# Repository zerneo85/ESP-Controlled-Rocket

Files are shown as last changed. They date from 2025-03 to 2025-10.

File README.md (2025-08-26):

# ESP Controlled Rocket

The ESP Controlled Rocket repository documents an advanced, ESP32-powered flight computer and 3D-printed rocket design. The project provides open-source firmware, electronics, and mechanical files to launch, track, and safely recover water rockets made from plastic bottles—ranging from simple mechanically-triggered parachute releases to full telemetry-enabled, software-controlled deployments.

---

## Table of Contents
- [ESP Controlled Rocket](#esp-controlled-rocket)
  - [Table of Contents](#table-of-contents)
  - [Introduction](#introduction)
  - [Rocket Variants](#rocket-variants)
    - [Rocket A](#rocket-a)
    - [Rocket B](#rocket-b)
  -  [Splicing Bottles](https://zerneo85.github.io/ESP-Controlled-Rocket/Water-Rocket-Splice-Bilingual.html)
- [ESP Controlled Rocket](#esp-controlled-rocket-1)
  - [Flight Computer](#flight-computer)
    - [Features](#features)
    - [LED Status Indicators](#led-status-indicators)
    - [Code Overview](#code-overview)
    - [Screenshots](#screenshots)
      - [Dashboard, File Manager, and Visualization](#dashboard-file-manager-and-visualization)
  - [3D Parts \& Downloads](#3d-parts--downloads)
    - [Parts Overview (Summary)](#parts-overview-summary)
  - [Assembly \& Build](#assembly--build)
  - [Usage](#usage)
    - [Setting Up the Flight Computer](#setting-up-the-flight-computer)
    - [Setting Triggers](#setting-triggers)
    - [SPIFFS Logging](#spiffs-logging)
  - [Rocket Performance (Simulation Results)](#rocket-performance-simulation-results)
    - [Water Rocket Performance Table (8 bar, realistic empty mass)](#water-rocket-performance-table-8-bar-realistic-empty-mass)
      - [Assumptions/Notes:](#assumptionsnotes)
  - [References \& Further Simulation](#references--further-simulation)
  - [Rocket Weight](#rocket-weight)
  - [Release Notes](#release-notes)
    - [v3.7.0](#v370)
  - [Contributing](#contributing)

---

## Introduction

The **ESP Controlled Rocket** project combines embedded firmware and printable parts for building water rockets with real-time telemetry, logging, and parachute deployment.  
There are two rocket builds:

- **Rocket A:** 1 bottle, mechanical parachute release (no electronics)
- **Rocket B:** 3 × 1.5L bottles, ESP32-based telemetry, automatic parachute deployment, and advanced data logging.

---

## Rocket Variants

### Rocket A

- Single PET bottle
- Mechanical parachute release
- See [docs/aircommandrockets_simulator_rocket_a.pdf](https://github.com/zerneo85/ESP-Controlled-Rocket/tree/main/docs/aircommandrockets_simulator_rocket_a.pdf) for simulation results

### Rocket B

- Three or more 1.5-liter PET bottles
- ESP32 flight computer with:
  - Telemetry (altitude, acceleration, orientation, etc.)
  - Web dashboard (WiFi)
  - Automatic and manual parachute deployment
  - Data logging (SD card + SPIFFS)
  - RGB LED status ring
  - **Automatic location/pressure/height fetching from OpenWeather API**
  - **Location and reference pressure/height can be updated on-the-fly from the web dashboard**
- See [docs/aircommandrockets_simulator_rocket_b.pdf](https://github.com/zerneo85/ESP-Controlled-Rocket/tree/main/docs/aircommandrockets_simulator_rocket_b.pdf) for simulation results

---

# ESP Controlled Rocket

...

## Flight Computer

### Features

- **Sensor Integration:**  
  - BMP280 (temperature, pressure, altitude)
  - MPU6050 (acceleration, gyroscope, temp)
- **Real-Time Telemetry:**  
  - WebSocket data streaming (altitude, acceleration, deployment state, battery, etc.)
- **Location & Atmospheric Reference:**  
  - **Automatically retrieves location and reference pressure/height from the OpenWeather API**
  - **Location and reference data can be updated live via the web dashboard** for accurate altitude and pressure calculations
- **Parachute Deployment:**  
  - Triggered by detected altitude drop or settable parameters
  - Manual override via dashboard
- **Dual Logging:**  
  - Logs flight and events to both SD card and SPIFFS (onboard flash)
  - Warns user if SPIFFS is full or nearly full
- **RGB LED Ring:**  
  - Multicolor status feedback for boot, WiFi, arming, flight, deployment, errors
- **OTA Updates:**  
  - Firmware can be updated via HTTP web interface
- **Web File Management:**  
  - Upload/download/delete files on SD card and SPIFFS
- **3D Visualization Support:**  
  - Streams orientation/telemetry for optional real-time display
  - **Since v3.7.0:** Visualization assets are stored directly in SPIFFS for faster access and easier deployment
- **Configurable Triggers:**  
  - Set altitude, descent, and arming conditions via web dashboard
- **Time Synchronization:**  
  - NTP for accurate timestamps
- **Flexible Axis Orientation:**  
  - Change IMU axes in software for different mounting positions
- **Improved Web Dashboard (v3.7.0):**  
  - Dashboard HTML, CSS, and JS files are now hosted from SPIFFS memory instead of flash-coding, reducing firmware size and simplifying updates.

...

### LED Status Indicators

The onboard RGB LED ring signals various states:

| State | LED Effect |
|---|---|
| Power-on/Boot | Spinning blue |
| Connecting to WiFi | Blinking yellow |
| Access Point mode | Blinking orange |
| WiFi Connected | Solid green |
| Arming parachute | Pulsing teal |
| Parachute armed (standby) | Solid blue |
| Parachute released | Red flash, then solid red |
| Logging active (SD/SPIFFS) | Brief white blink on each write |
| Error (sensor, SD, SPIFFS) | Flashing red |
| OTA update in progress | Spinning purple |
| SPIFFS almost full | Alternating red/white flash |
| SPIFFS/SD full or write fail  | Fast flashing red |

**Note:** All LED sequences are customizable in the firmware.

---

### Code Overview

The main firmware is organized as follows:

- **Sensor Management**  
  Handles initialization, calibration, and continuous reading of BMP280 and MPU6050 sensors. Includes zeroing/calibration routines (triggered via dashboard) and monitoring for sensor errors or drift.
- **Data Processing**  
  Processes raw sensor data: applies filtering, calculates true altitude (using local or API pressure reference), computes speed, acceleration, and detects launch/apogee/descent events. Also manages state transitions for arming and flight.
- **Parachute Control**  
  Evaluates trigger logic for parachute release based on configurable parameters (altitude drop, time, speed, etc.), and actuates the servo. Also handles manual overrides.
- **LED Status Indicators**  
  Drives the RGB LED ring with appropriate effects for all operational, error, and feedback states.
- **Communication**  
  Runs a web server and WebSocket interface for live telemetry, file management, trigger config, and OTA updates.
- **Web-Based File Management**  
  Lets you view, upload, download, or delete files from both SD card and SPIFFS through the web UI ([flight-computer/data/index.html](https://github.com/zerneo85/ESP-Controlled-Rocket/tree/main/flight-computer/data/index.html)).
- **3D Visualization Support**  
  Broadcasts orientation/quaternion and motion data for an optional web-based real-time 3D rocket visualization (experimental).
- **Logging**  
  Logs all flight events, sensor data, state transitions, and errors to SD card and SPIFFS, with backup and rollover if space runs out. Warns if SPIFFS is almost full.
- **Configurable Axis Orientation**  
  IMU axes can be reassigned at runtime via the dashboard for flexible installation.
- **Live Location Overrides**  
  Location (lat/lon) and pressure reference can be set/changed from the web interface, which updates all altitude and weather calculations instantly.  
- **OTA Updates**  
  Supports uploading new firmware from the web interface, including status feedback via LED.

See [`flight-computer/flight-computer.ino`](https://github.com/zerneo85/ESP-Controlled-Rocket/tree/main/flight-computer/flight-computer.ino) and related modules for implementation details.

---

### Screenshots

#### Dashboard, File Manager, and Visualization
All dashboards video  
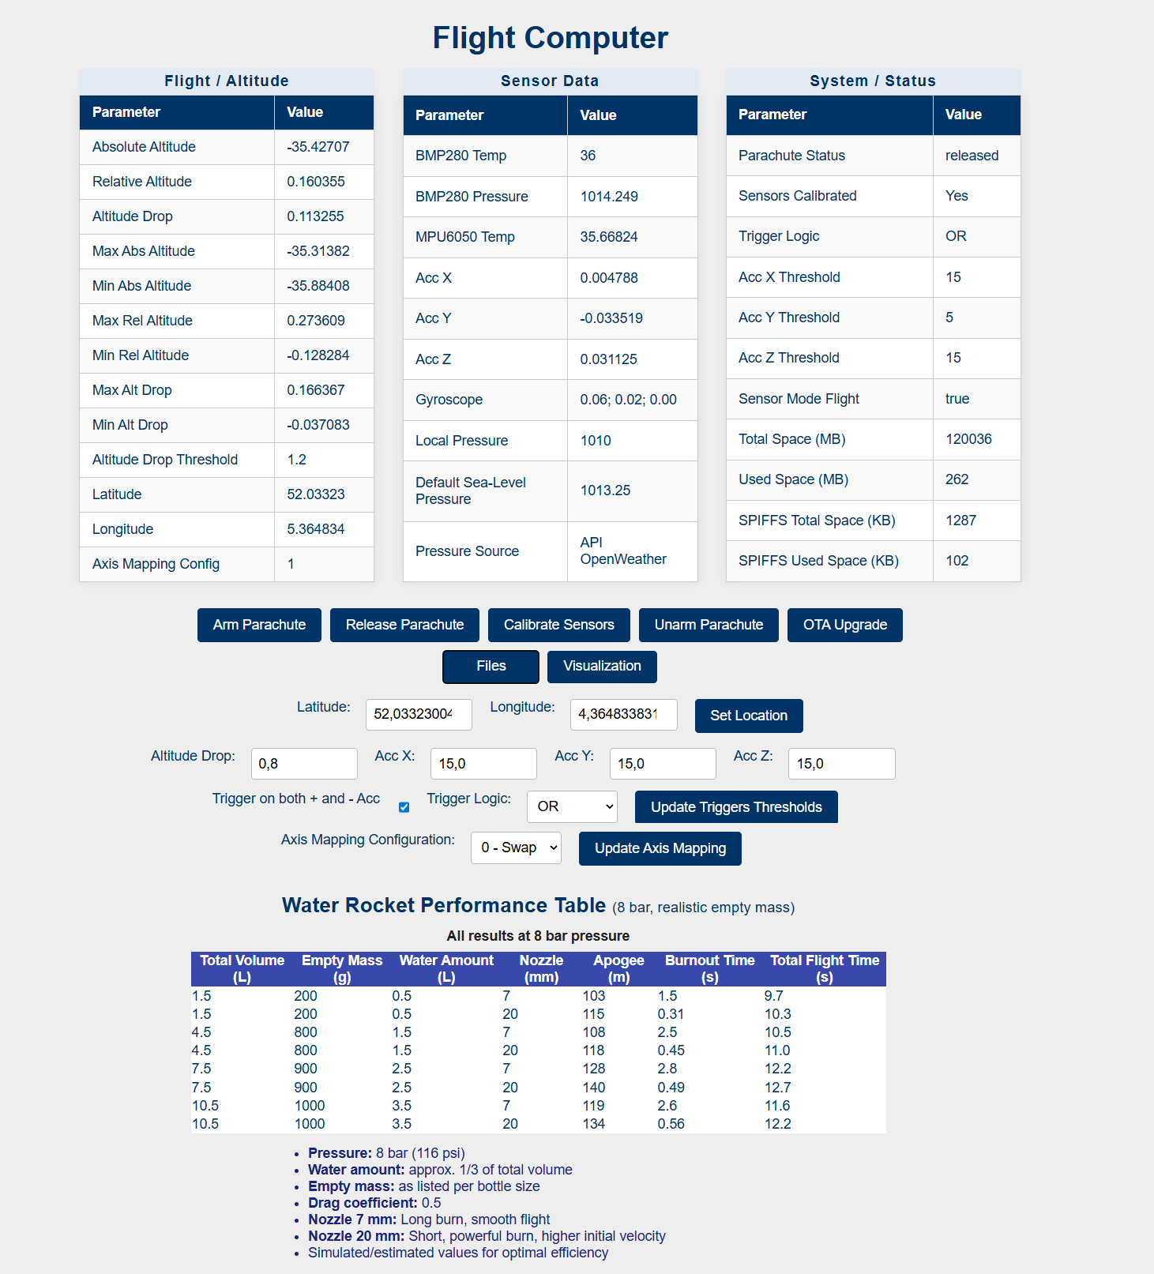
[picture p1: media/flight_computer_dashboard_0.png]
Flight Computer Screenshot
  
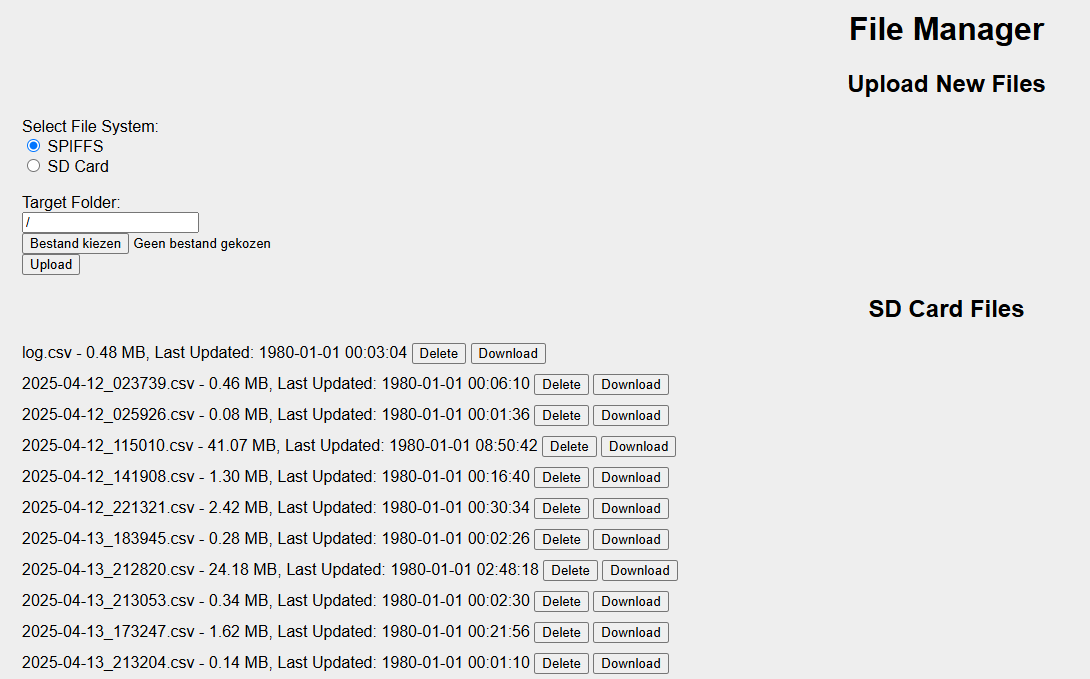
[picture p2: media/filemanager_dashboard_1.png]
File Manager Screenshot
  
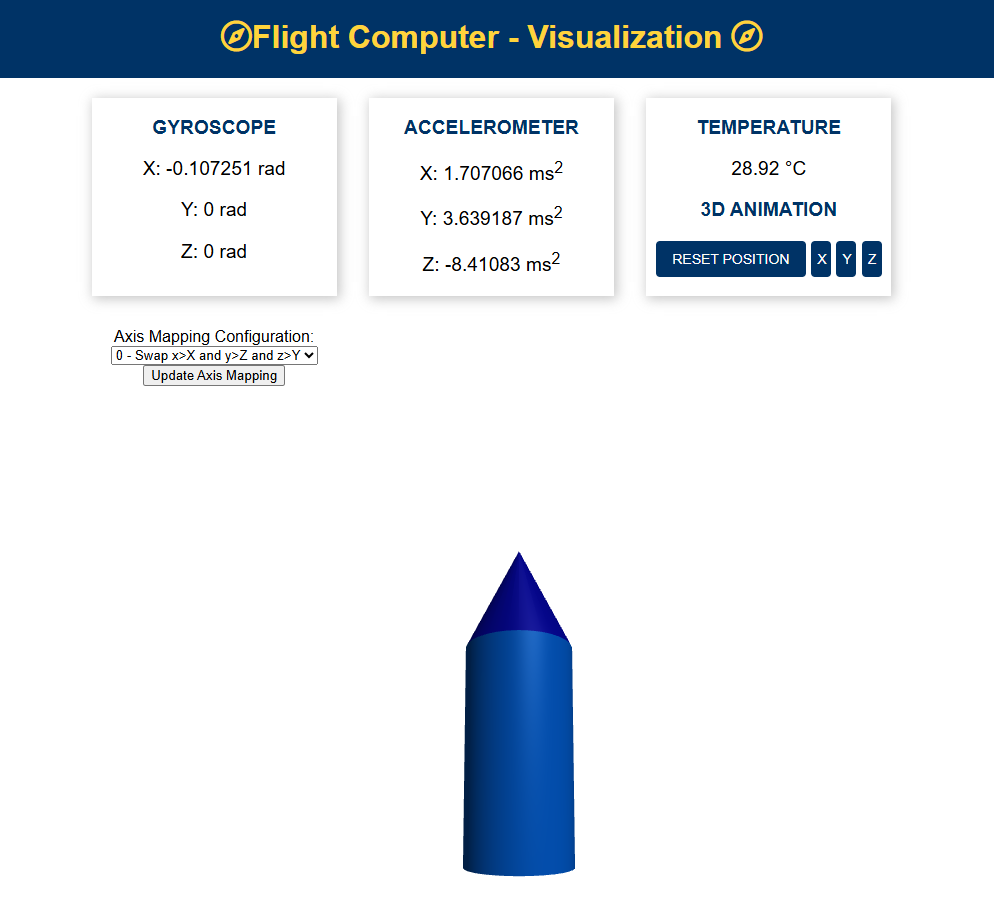
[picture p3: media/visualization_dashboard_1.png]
Visualization Screenshot
  
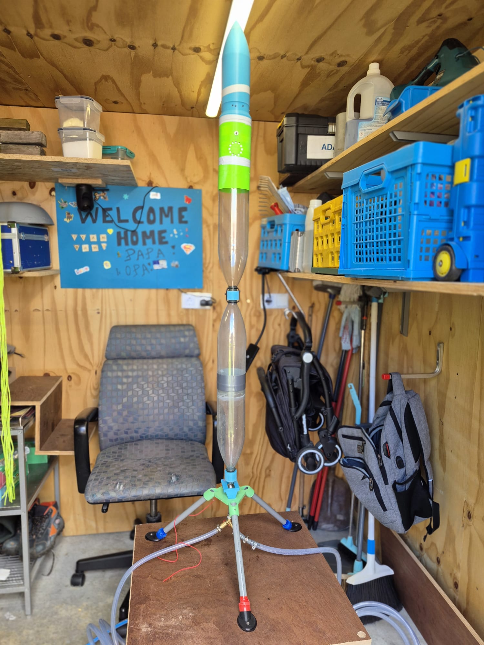
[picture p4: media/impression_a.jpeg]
Impression A
 
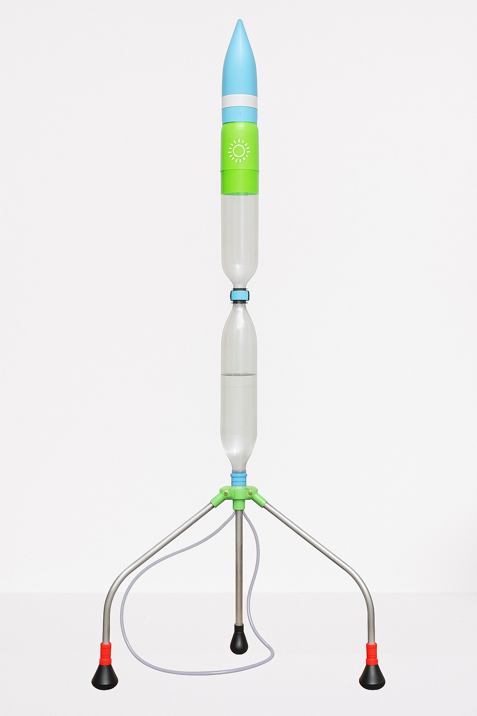
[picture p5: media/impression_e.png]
Impression E
  
Payload Parachute Release Video  

---

## 3D Parts & Downloads

All 3D-printable parts for the ESP Controlled Rocket are available:

- **Repository:** [`/3d-designs/`](https://github.com/zerneo85/ESP-Controlled-Rocket/tree/main/3d-designs/) – STL files with exact filenames as listed
- **Tinkercad Project:** [Soda Water Bottle Rocket Air Pressure](https://www.tinkercad.com/things/2OLB51qPn6D-soda-bottle-rocket-air-pressure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)  
  *(note: transparent parts represent older versions)*
- **Thingiverse:** [Soda Water Bottle Rocket Air Pressure](https://www.thingiverse.com/thing:7127173)

### Parts Overview (Summary)

Below is a categorized overview of the 3D-printable parts.  
For the **complete list with detailed descriptions and references**, see [docs/3d_parts_overview.md](https://github.com/zerneo85/ESP-Controlled-Rocket/tree/main/docs/3d_parts_overview.md).

| Use Category | Colors |
|---|---|
| Bottle & Nozzle & Hose Connectors | Orange |
| Fins | Dark Purple, Light Purple |
| Launching Platform Air Pressure Release | Dark Green |
| Launching Platform Cable Tie Release  | Green |
| Parachute Ejection Module | Blue |
| Payload Enclosure | Yellow |
| Rail Guide Mount | Red |
| Servo Arms | Light Green |
| Simple Rocket & Parachute Module | Gray |

---

## Assembly & Build

See [`docs/assembly_guide.md`](https://github.com/zerneo85/ESP-Controlled-Rocket/tree/main/docs/assembly_guide.md) for wiring, assembly, and mounting tips.

---

## Usage

### Setting Up the Flight Computer

1. **WiFi Configuration:**  
   - Edit WiFi credentials in [`flight-computer/flight-computer.ino`](https://github.com/zerneo85/ESP-Controlled-Rocket/tree/main/flight-computer/flight-computer.ino)
   - If WiFi fails, device enters Access Point mode (see [LED Status Indicators](#led-status-indicators))

2. **Calibrating Sensors:**  
   - Use the dashboard to trigger IMU and barometric sensor calibration/zeroing.
   - Axis alignment (for IMU) can be changed from the web interface and saved for next boot.

3. **Changing Axis / IMU Orientation:**  
   - In the dashboard, select the mounting orientation that matches your build.
   - The firmware applies the corresponding transformation to all motion data.

4. **Changing Triggers:**  
   - All parachute triggers (arming/release altitude, speed, time) can be set via the web interface, or changed in the config section of [`flight-computer.ino`](https://github.com/zerneo85/ESP-Controlled-Rocket/tree/main/flight-computer/flight-computer.ino).

5. **Changing Location & Weather Reference:**  
   - Update launch site coordinates and pressure reference directly from the dashboard.
   - Device can fetch current weather/pressure using the OpenWeather API.
   - All calculations (altitude, apogee, trigger) immediately reflect the new data.

6. **3D Visualization:**  
   - Enable the real-time 3D view from the web UI for attitude/flight path visualization.

7. **OTA Updates:**  
   - Web-based firmware upload (see dashboard)

8. **Manual Parachute Release:**  
   - Use “Arm” and “Release” buttons on the web dashboard

9. **File Management:**  
   - Upload/download/delete logs via the web interface (SD + SPIFFS)

---

### Setting Triggers

All parachute release and arming triggers are **configurable via the web dashboard**:

- **Arming:** Set minimum altitude, minimum time after launch, or minimum vertical speed
- **Release:** Configure required altitude drop (relative or absolute), minimum speed, and/or custom sensor thresholds
- **Manual override** is always available from the dashboard

To change default trigger parameters in code, edit the config section in [`flight-computer/flight-computer.ino`](https://github.com/zerneo85/ESP-Controlled-Rocket/tree/main/flight-computer/flight-computer.ino).

---

### SPIFFS Logging

- **All critical events and telemetry** are logged to both SD card and SPIFFS (flash memory) as backup.
- If SPIFFS free space drops below 10%, a **red/white alternating LED flash** warns the user. If full, **fast red flashing** and a dashboard warning are triggered; logging pauses until space is freed.
- SPIFFS logs can be downloaded/deleted from the File Manager page in the web UI.
- **Since v3.7.0:** The complete web dashboard and visualization interface are also stored in SPIFFS. This enables updates of UI components without reflashing the firmware.

---

## Rocket Performance (Simulation Results)

Full details for both rocket builds are in the simulation PDFs, generated with [Air Command Rocket Simulator](http://www.aircommandrockets.com/sim/simulator.htm):

| Variant | PDF | Volume (L) | Water (L) | Empty Mass (g) | Nozzle (mm) | Peak Altitude (m) | Notes |
|---|--- |--- |--- |--- |--- |--- |---|
| Rocket A  | [docs/aircommandrockets_simulator_rocket_a.pdf](https://github.com/zerneo85/ESP-Controlled-Rocket/tree/main/docs/aircommandrockets_simulator_rocket_a.pdf) | 1.5 | 0.5 | 198 | 7 | 67.7 | Mechanical  |
| Rocket B  | [docs/aircommandrockets_simulator_rocket_b.pdf](https://github.com/zerneo85/ESP-Controlled-Rocket/tree/main/docs/aircommandrockets_simulator_rocket_b.pdf) | 4.5 | 1.0 | 803 | 7 | 50.0 | ESP32/auto  |

- *See PDFs in [`docs/`](https://github.com/zerneo85/ESP-Controlled-Rocket/tree/main/docs/) for full simulation graphs and breakdown.*
- *For further/different setups, use the [Air Command Rocket Simulator](http://www.aircommandrockets.com/sim/simulator.htm).*

### Water Rocket Performance Table (8 bar, realistic empty mass)

| Total Volume (L) | Empty Mass (g) | Water Amount (L) | Nozzle (mm) | Apogee (m) | Burnout Time (s) | Total Flight Time (s) |
|:---:|:---:|:---:|:---:|:---:|:---:|:---:|
| 1.5 | 200 | 0.5 | 7 | 103 | 1.5 |  9.7 |
| 1.5 | 200 | 0.5 | 20 | 115 | 0.31 |  10.3 |
| 4.5 | 800 | 1.5 | 7 | 108 | 2.5 |  10.5 |
| 4.5 | 800 | 1.5 | 20 | 118 | 0.45 |  11.0 |
| 7.5 | 900 | 2.5 | 7 | 128 | 2.8 |  12.2 |
| 7.5 | 900 | 2.5 | 20 | 140 | 0.49 |  12.7 |
| 10.5 | 1000 | 3.5 | 7 | 119 | 2.6 |  11.6 |
| 10.5 | 1000 | 3.5 | 20 | 134 | 0.56 |  12.2 |

#### Assumptions/Notes:
- Pressure: **8 bar** (116 psi)
- Water amount: ~**1/3 of total volume**
- Empty mass: As shown for each bottle size
- Drag coefficient: **0.5**
- Nozzle: **7 mm** (long burn, smooth flight), **20 mm** (short, powerful burn, higher velocity)
- Simulated/estimated values (for best-case efficiency)

---

## References & Further Simulation

- [Air Command Rocket Simulator](http://www.aircommandrockets.com/sim/simulator.htm) – Advanced web-based tool for bottle rocket performance prediction and optimization
- [`docs/aircommandrockets_simulator_rocket_a.pdf`](https://github.com/zerneo85/ESP-Controlled-Rocket/tree/main/docs/aircommandrockets_simulator_rocket_a.pdf) (Rocket A)
- [`docs/aircommandrockets_simulator_rocket_b.pdf`](https://github.com/zerneo85/ESP-Controlled-Rocket/tree/main/docs/aircommandrockets_simulator_rocket_b.pdf) (Rocket B)

---

## Rocket Weight

See [`docs/rocket_parts.xlsx`](https://github.com/zerneo85/ESP-Controlled-Rocket/tree/main/docs/rocket_parts.xlsx) for weight of the individual parts.

## Release Notes

### v3.7.0
- Moved **dashboard and visualization files** into **SPIFFS memory**:
  - Frees up firmware space  
  - Allows updating of UI components via SPIFFS file manager  
  - Faster load times for dashboards and visualizations
- Improved maintainability by separating UI assets from firmware code
- Minor bug fixes and optimizations

## Contributing

Contributions are welcome! Please:
- Fork the repository
- Use feature branches
- Write clear commit messages
- Submit pull requests with a detailed description

---

_Questions, suggestions, or want extra details? Open an issue or reach out!_

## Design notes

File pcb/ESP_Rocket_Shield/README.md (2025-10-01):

# ESP Rocket Shield — KiCad Starter Project (Rev A)

This is a **starter** KiCad 8 project for your ESP32‑S3 rocket shield. It includes a schematic with all blocks you requested (power with L7805, I²C sensors (BMP280/MPU6050 class), LED pads, piezo buzzer, and dual female headers for the ESP32‑S3 dev board). 
The PCB file contains the board outline and class definitions; import/update from the schematic to populate footprints as you finalize.

> **Note**: This scaffold is intentionally minimal so you can adjust footprints to your exact parts. Nets, labels, and blocks are provided; please run **Tools → Annotate**, then **Assign Footprints**, then **Update PCB from Schematic**.

## Quick steps
1. Open `ESP_Rocket_Shield.kicad_pro` in KiCad 8+.
2. Open the schematic. Check/replace sensor symbols if you choose BMP388/DPS310/ICM‑42688 instead of BMP280/MPU6050.
3. Use **Assign Footprints** to bind footprints that match your inventory (headers, LGA packages, buzzer, etc.).
4. Run **Update PCB from Schematic** to bring parts into PCB.
5. Route, pour GND, add stitching vias, and finalize thermals on L7805.
6. Generate Gerbers.

## Nets / pins (matches your firmware & diagram)
- LED data: **GPIO17** → `LED_DATA` → series **330 Ω** → LED pad.
- I²C: **GPIO42= SDA**, **GPIO37= SCL**, with **4.7 kΩ** pull‑ups to **3V3**.
- Buzzer: **GPIO21** → 1 kΩ → N‑MOSFET/NPN → Active buzzer to **+5V**.
- Servo (optional): **GPIO14** → 3‑pin header (+5V / PWM / GND).
- Power: **VIN** (2S Li‑ion) → Fuse → Schottky (reverse) → **L7805** → **+5V** rail.
- ESP32 gets power via **5V** dev board pin; sensors on **3V3** from the dev board.

## Library picks
- L7805: `Regulator_Linear:L7805` symbol; footprint TO‑220 or TO‑252.
- Baro: `Sensor_Pressure:BMP280` (swap to BMP388/DPS310 later if you prefer).
- IMU: `Sensor_Motion:MPU-6050` (swap to ICM‑42688‑P if you prefer).
- Headers: `Connector_Generic:Conn_01x19_Female` left/right for ESP32‑S3; `Conn_01x03` for LED and Servo.
- Buzzer driver: `Device:Q_NMOS_GSD` (2N7002) or `Device:Q_NPN_BEC` (MMBT2222A).

## Board outline
The PCB is initialized as 90×40 mm with 4× M2.5 mounting holes. Adjust to fit your airframe.

## Notes
- Place the IMU and barometer near the board center, away from the buzzer and power edges.
- Keep a vent hole under the barometer and cover with open‑cell foam after assembly.
- If LED current > ~0.6–0.8 A and VIN ≈ 2S (7–8.4 V), consider swapping L7805 for a buck converter footprint to reduce heat.

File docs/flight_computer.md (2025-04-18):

# Flight Computer Documentation

This document provides a detailed explanation of the flight computer firmware used in the ESP Controlled Rocket project. It covers architecture, sensor integration, core functionalities, and software modules.

> **Note:** Version **3.4.0** adds web-based file management, optional 3D visualization, axis configuration, and live location updates. Camera/timelapse functionality is removed.

## Table of Contents

- [Introduction](#introduction)  
- [System Architecture](#system-architecture)  
- [Sensor Integration](#sensor-integration)  
- [Core Functionalities](#core-functionalities)  
- [Software Modules](#software-modules)  
- [Code Structure Overview](#code-structure-overview)  
- [Recent Improvements](#recent-improvements)  
- [Troubleshooting](#troubleshooting)  
- [References](#references)

---

## Introduction

Runs on ESP32; handles sensor data, parachute control, telemetry, logging, and OTA updates.

---

## System Architecture

- **ESP32** with SD_MMC  
- **BMP280** & **MPU6050** via I2C  
- **Servo** for parachute  
- **RGB LED Ring** for status  
- **WiFi/WebSocket** for dashboard & commands  
- **SPIFFS & SD** for storage

Architecture

---

## Sensor Integration

### BMP280  
- Altitude via barometric formula; uses live location override for reference pressure.

### MPU6050  
- IMU data; supports runtime axis remapping via web UI.

---

## Core Functionalities

### Data Acquisition  
- Absolute & relative altitude, corrected altitude drop.

### Parachute Control  
- Arm via web; automatic/manual release; logs events.

### Web Server & Telemetry  
- Dashboard, WebSockets, axis config, location override, optional 3D viz data.

### Logging & Storage  
- Web file manager (upload/download/delete SPIFFS & SD), SD logging, serial debug.

### OTA & Connectivity  
- Station/AP mode, HTTP OTA (`/update`), mDNS, LED status patterns.

---

## Software Modules

- Sensor Management  
- Data Processing  
- Parachute Control  
- LED Indicators  
- Communication (HTTP & WS)  
- Logging  
- Utilities

---

## Code Structure Overview

- **Globals & Includes**  
- **setup()**: init WiFi, SD, sensors, server, WS, LED ring  
- **loop()**: handleClient, webSocket.loop, read sensors, compute, log, broadcast  
- **webSocketEvent()**: process commands (arm/release, axis config, location)  
- **Helper functions**: armParachute(), releaseParachute(), updateOrientation(), updateLocation(), setLEDStatus()

---

## Recent Improvements

- **Web File Manager** (SPIFFS & SD)  
- **Optional 3D Visualization** data stream  
- **Runtime Axis Configuration**  
- **Live Location Updates**  
- **Removed Camera/Timelapse**  
- **Altitude Drop Refinement**  
- **RGB LED Enhancements**

---

## Troubleshooting

- Check I2C wiring & axis settings  
- Verify WiFi/AP connectivity & IP/mDNS  
- Ensure SD card format & wiring  
- Test servo power & movement  

---

## References

- Adafruit BMP280 & MPU6050 libraries  
- ESP32 WebServer & WebSocket libraries  
- Arduino OTA docs  
- OpenWeatherMap API

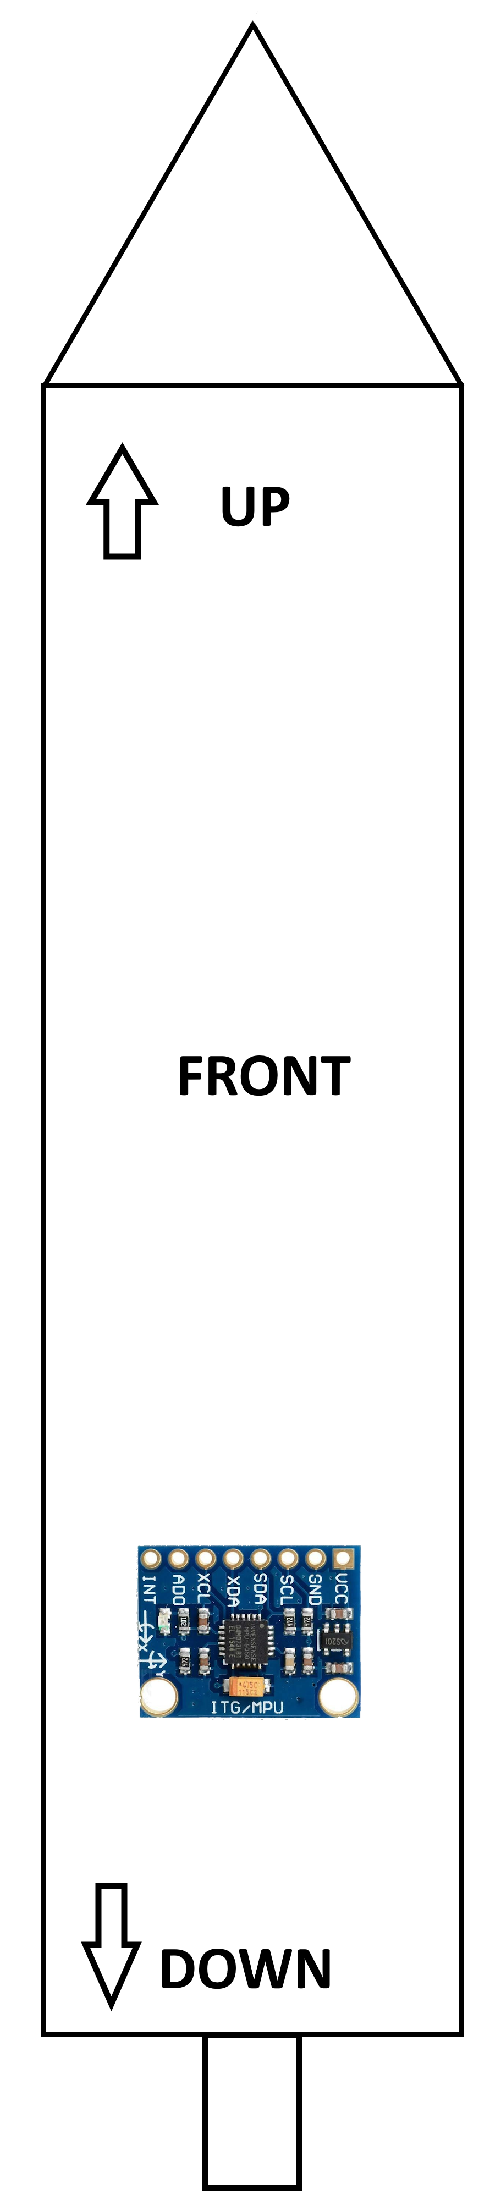
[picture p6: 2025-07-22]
media/Rocket-Overview Sensor.png

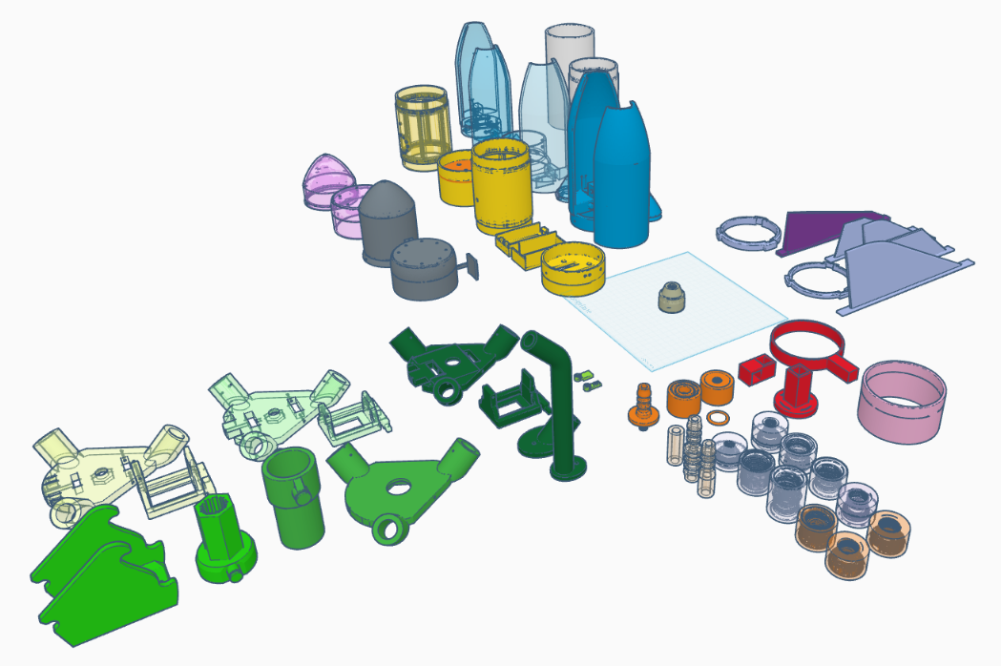
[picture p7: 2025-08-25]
media/tinkercad_overview.png

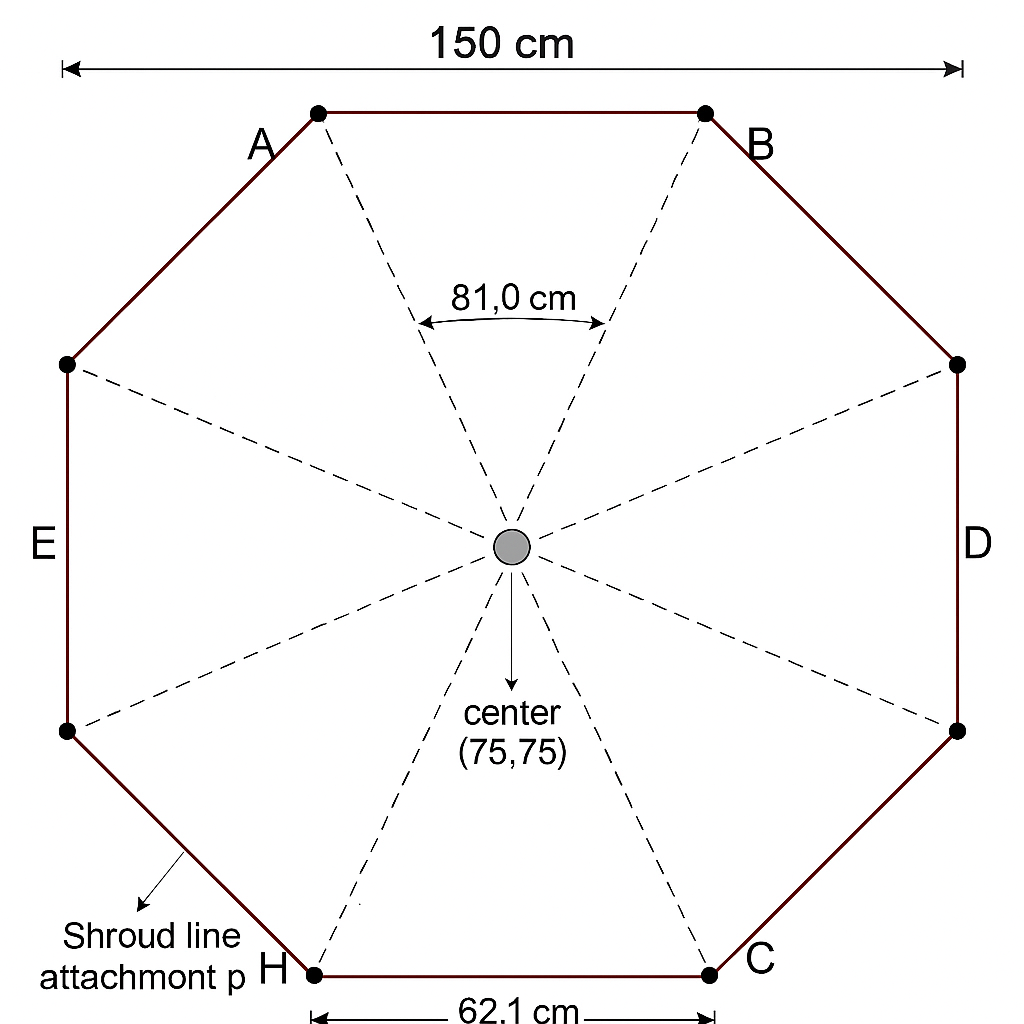
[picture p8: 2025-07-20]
media/parachute_design.png

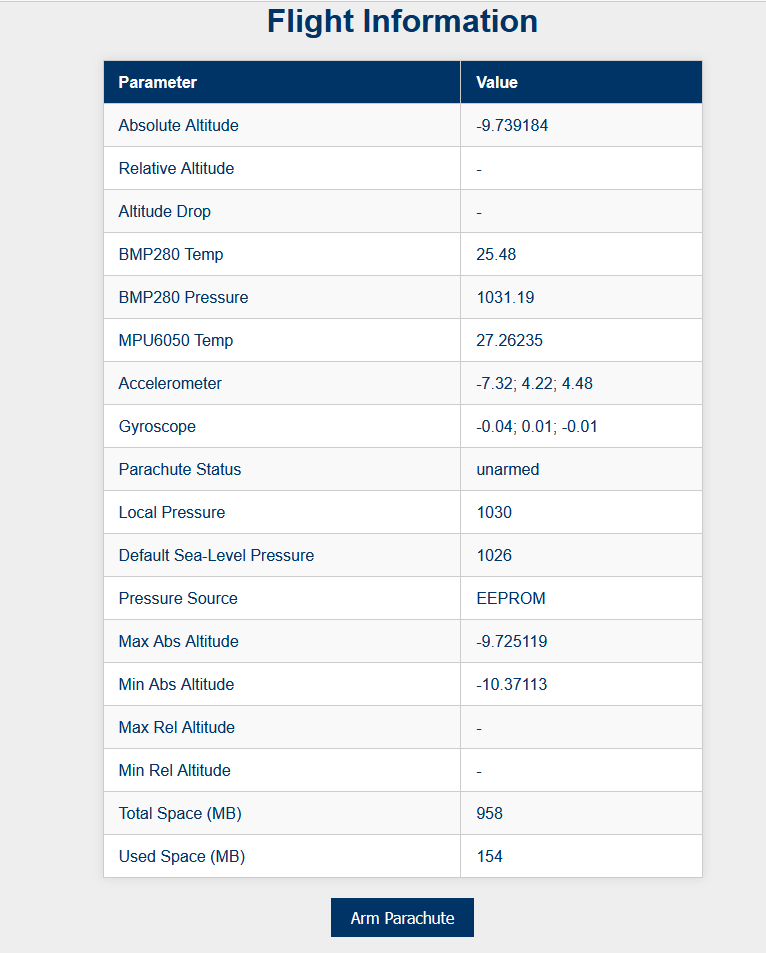
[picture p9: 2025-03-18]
media/flight_computer_dashboard_2.png

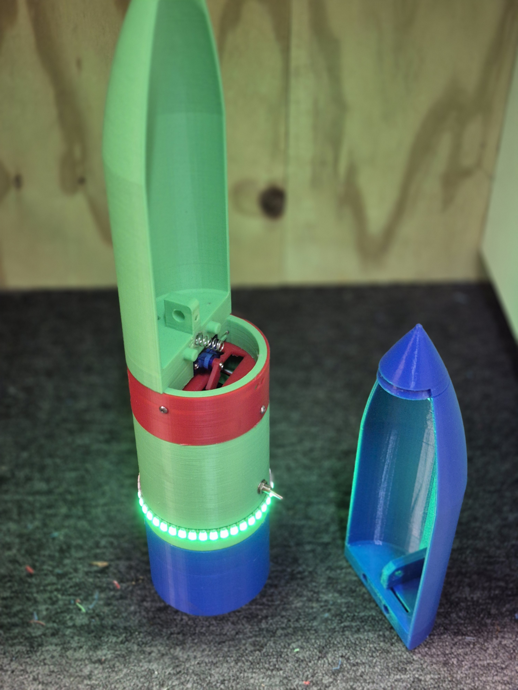
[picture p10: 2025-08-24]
media/Payload_Parachute_Nose_Cone.jpg

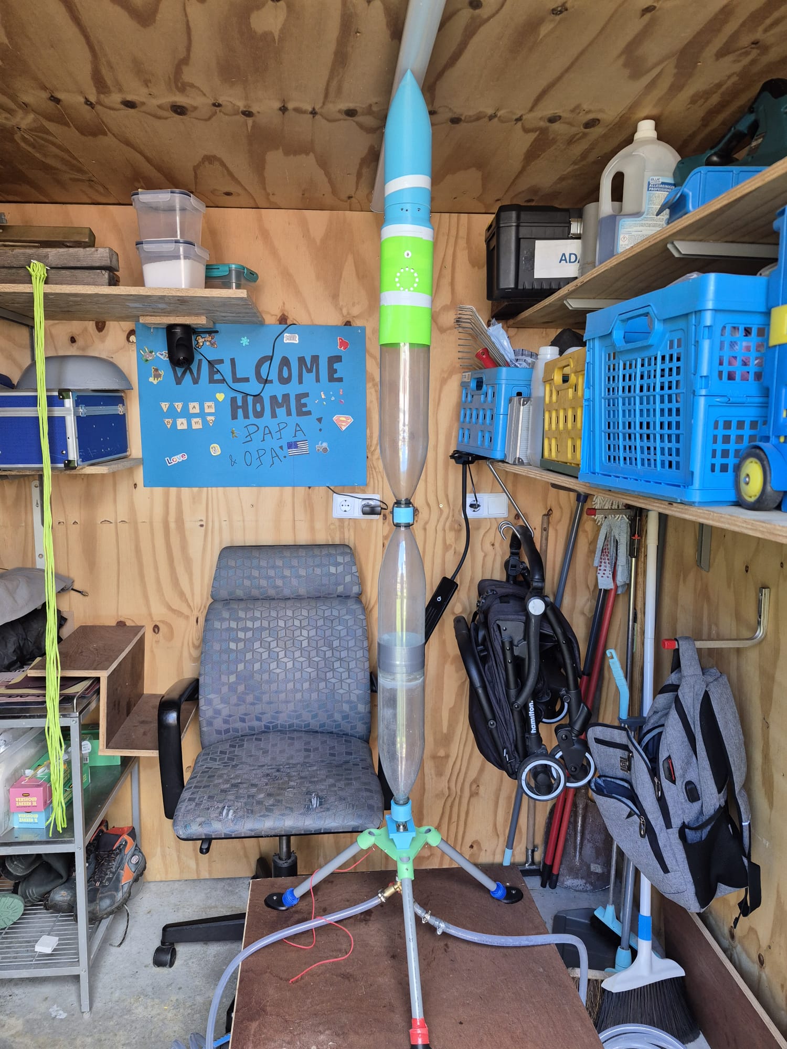
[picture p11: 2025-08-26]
media/impression_c.jpeg

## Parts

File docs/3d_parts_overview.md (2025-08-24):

# 3D Parts Overview

This document lists all 3D-printable parts used in the ESP Controlled Rocket project.

## Parts Table

| Part | Color | Use | Description | Remix |
|:---|:---|:---|:---|:---|
| Fins Ring Type 1 Heavy | Light Purple | Fins | Customized Fin Ring | – |
| Fins Ring Type 1 Light | Light Purple | Fins | Customized Fin Ring half the height to save weight | – |
| Fin Type 1 A | Dark Purple  | Fins | Orignal downloaded Fin corrected for size | https://www.thingiverse.com/thing:3642349 |
| Fin Type 1 B | Light Purple | Fins | Orignal downloaded Fin corrected for size, shape Triangle | – |
| Fin Type 1 C | Light Purple | Fins | Orignal downloaded Fin corrected for size, shape Round | – |
| Fin Type 1 D | Light Purple | Fins | Orignal downloaded Fin corrected for size, shape Square | – |
| Fin Type 1 C Large | Light Purple | Fins | Orignal downloaded Fin corrected for size,shape Round, Large | – |
| Rail Guide Mount Foot | Red | Rail Guide Mount | Rail Guide Mount Foot to screw in base and slide in square rails | – |
| Rail Guide Mount Slider | Red | Rail Guide Mount | Rail Guide Mount Slider to slide the ring up and down in the rails | – |
| Rail Guide Mount Ring | Red | Rail Guide Mount | Rail Guide Mount Ring to hold body rocket straight | – |
| Hose Connector Compressed Air Pomp | Orange | Bottle & Nozzle & Hose Connectors | Hose Connector Compressed Air Pomp to transiation from default valve to hose | – |
| Bottle Connector | Orange | Bottle & Nozzle & Hose Connectors | Improved bottle connector where a o ring slides between the walls and where the bottle screws in | – |
| Valve Connector | Orange | Bottle & Nozzle & Hose Connectors | Improved bottle connector where a o ring slides between the walls and where the Air Pressure Quick release threads into | – |
| Servo Motor Arm Type 1 | Light Green  | Servo Arms | Servo Motor Arm Type 1 where round arm is squared | – |
| Servo Motor Arm Type 2 | Light Green  | Servo Arms | Servo Motor Arm Type 1 where round arm is squared en extended | – |
| Launch Platform Base Air pressure Quick release | Dark Green | Launching Platform Air Pressure Release | Customized Raketfuedrockets PodPad Launch Platform Base for Air pressure Quick release BSP Euro line | https://www.raketfuedrockets.com/en/3dprinting.htm#xl_PodPad |
| Launch Platform Foot | Dark Green | Launching Platform Air Pressure Release | PodPad Launch Platform Foot | https://www.raketfuedrockets.com/en/3dprinting.htm#xl_PodPad |
| Launch Platform Leg | Dark Green | Launching Platform Air Pressure Release | Launch Platform Leg | – |
| Launch Platform Air pressure Quick release Trigger | Dark Green | Launching Platform Air Pressure Release | Customized Raketfuedrockets PodPad Launch Platform Qucik Release for Air pressure BSP Euro line | https://www.raketfuedrockets.com/en/3dprinting.htm#xl_PodPad |
| Launch Platform Base Air pressure Cable Tie | Green | Launching Platform Cable Tie Release | Customized Raketfuedrockets PodPad Launch Platform Base for Air pressure Cable Tie | https://www.raketfuedrockets.com/en/3dprinting.htm#xl_PodPad |
| Launch Platform Air pressure Cable Tie Trigger | Green | Launching Platform Cable Tie Release | Standard Cable Tie Trigger | https://www.thingiverse.com/thing:2835346 |
| Launch Platform Air pressure Cable Tie Holder | Green | Launching Platform Cable Tie Release | Standard Cable Tie Holder | https://www.thingiverse.com/thing:2835346 |
| Launch Platform Air pressure Cable Tie Solder | Green | Launching Platform Cable Tie Release | Standard Cable Tie Slider | https://www.thingiverse.com/thing:2835346 |
| Flight Computer Mount | Yellow | Payload Enclosure | Mount for ESP32 controller | – |
| Battery Mount | Yellow | Payload Enclosure | Mount for 3000 mAh Li-On Battery 7.4 V | – |
| Payload Bottle Connector Type B | Yellow | Payload Enclosure | Connector between top of bottle and and Payload Body | – |
| Payload Body | Yellow | Payload Enclosure | Payload body with small rails to mount ESP and Battery | – |
| Payload Nose Connector | Yellow | Payload Enclosure | Connector between top of the Payload Body and the Nose | – |
| Nose Cone Tip | Blue | Parachute Ejection Module | Nose Cone Tip of the parachute eject system | https://www.thingiverse.com/thing:4564390 |
| Nose Cone Body Type B | Blue | Parachute Ejection Module | Nose Cone Body of the parachute eject system that slides over body | https://www.thingiverse.com/thing:4564390 |
| Nose Cone Ejection Hatch | Blue | Parachute Ejection Module | Nose Cone Ejection hach of the parachute eject system | https://www.thingiverse.com/thing:4564390 |
| Payload Bottle Connector Type A | Gray | Simple Rocket & Parachute Module | Connector between top of bottle and and Parachute Body | https://www.thingiverse.com/thing:294758 |
| Nose Cone Body Type A | Gray | Simple Rocket & Parachute Module | Nose Cone Body of the parachute eject system that connects to Payload Bottle Connector Type A | https://www.thingiverse.com/thing:294758 |

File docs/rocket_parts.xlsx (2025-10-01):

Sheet: Weight
Part | Weight (grams) | # Parts 1,5 L Rocket A | Total Weight 1,5 L Rocket A | # Parts 4,125 L Rocket B | Total Weight 4,125 L Rocket B | # Parts 6,75 L Rocket B | Total Weight 6,75 L Rocket B | # Parts 9,375 L Rocket B | Total Weight 9,375 L Rocket B | # Parts 12 L Rocket B | Total Weight 12 L Rocket B | # Parts 12 L Rocket C | Total Weight 12 L Rocket C | # Parts 12 L Rocket D | Total Weight 12 L Rocket D | # Parts 12 L Rocket E | Total Weight 12 L Rocket E
Nozzle A | 19 | 1 | 19 | 1 | 19 | 1 | 19 | 1 | 19 | 1 | 19 | 1 | 19 | 0 | 0 | 0 | 0
Nozzle Connector A/B/C | 23 | 1 | 23 | 1 | 23 | 1 | 23 | 1 | 23 | 1 | 23 | 1 | 23 | 0 | 0 | 0 | 0
Nozzle + Connector D | 12 | 0 | 0 | 0 | 0 | 0 | 0 | 0 | 0 | 0 | 0 | 0 | 0 | 1 | 12 | 0 | 0
Nozzle + Connector E | 14 | 0 | 0 | 0 | 0 | 0 | 0 | 0 | 0 | 0 | 0 | 0 | 0 | 0 | 0 | 1 | 14
Bottle Connector | 26 | 0 | 0 | 1 | 26 | 2 | 52 | 3 | 78 | 4 | 104 | 4 | 104 | 4 | 104 | 4 | 104
Bottle | 41 | 1 | 41 | 1 | 41 | 1 | 41 | 1 | 41 | 1 | 41 | 1 | 41 | 1 | 41 | 1 | 41
Spliced Bottles | 80 | 0 | 0 | 1 | 80 | 2 | 160 | 3 | 240 | 4 | 320 | 4 | 320 | 4 | 320 | 4 | 320
Payload Bottle Connector Type A | 43 | 1 | 43 | 0 | 0 | 0 | 0 | 0 | 0 | 1 | 43 | 0 | 0 | 0 | 0 | 0 | 0
Payload Bottle Connector Type B | 47 | 0 | 0 | 1 | 47 | 1 | 47 | 1 | 47 | 0 | 0 | 0 | 0 | 0 | 0 | 0 | 0
Payload Bottle Connector Type C | 40 | 0 | 0 | 0 | 0 | 0 | 0 | 0 | 0 | 0 | 0 | 1 | 40 | 0 | 0 | 0 | 0
Payload Bottle Connector Type D | 26 | 0 | 0 | 0 | 0 | 0 | 0 | 0 | 0 | 0 | 0 | 0 | 0 | 1 | 26 | 0 | 0
Payload Bottle Connector + Body + Payload +FC + Bat + Para + EH Type E | 400 | 0 | 0 | 0 | 0 | 0 | 0 | 0 | 0 | 0 | 0 | 0 | 0 | 0 | 0 | 1 | 400
Payload Body A/B/C | 74 | 0 | 0 | 1 | 74 | 1 | 74 | 1 | 74 | 0 | 0 | 0 | 0 | 0 | 0 | 0 | 0
Payload Body D | 40 | 0 | 0 | 0 | 0 | 0 | 0 | 0 | 0 | 0 | 0 | 0 | 0 | 1 | 40 | 0 | 0
Flight Computer | 40 | 0 | 0 | 1 | 40 | 1 | 40 | 1 | 40 | 0 | 0 | 1 | 40 | 1 | 40 | 0 | 0
Flight Computer Mount A/B/C | 7 | 0 | 0 | 1 | 7 | 1 | 7 | 1 | 7 | 0 | 0 | 0 | 0 | 0 | 0 | 0 | 0
Flight Computer Mount D | 4 | 0 | 0 | 0 | 0 | 0 | 0 | 0 | 0 | 0 | 0 | 0 | 0 | 1 | 4 | 0 | 0
Battery | 97 | 0 | 0 | 1 | 97 | 1 | 97 | 1 | 97 | 0 | 0 | 1 | 97 | 1 | 97 | 0 | 0
Battery Mount A/B/C | 8 | 0 | 0 | 1 | 8 | 1 | 8 | 1 | 8 | 0 | 0 | 0 | 0 | 0 | 0 | 0 | 0
Parachute Small 65cm | 26 | 1 | 26 | 0 | 0 | 0 | 0 | 0 | 0 | 1 | 26 | 0 | 0 | 0 | 0 | 0 | 0
Parachute Medium 90cm | 66 | 0 | 0 | 1 | 66 | 1 | 66 | 1 | 66 | 0 | 0 | 1 | 66 | 1 | 66 | 0 | 0
Parachute Large 150cm | 100 | 0 | 0 | 0 | 0 | 0 | 0 | 0 | 0 | 0 | 0 | 0 | 0 | 0 | 0 | 0 | 0
Nose Cone Tip A | 42 | 0 | 0 | 1 | 42 | 1 | 42 | 1 | 42 | 0 | 0 | 0 | 0 | 0 | 0 | 0 | 0
Nose Cone Tip C | 10 | 0 | 0 | 0 | 0 | 0 | 0 | 0 | 0 | 0 | 0 | 1 | 10 | 0 | 0 | 0 | 0
Nose Cone Tip D | 25 | 0 | 0 | 0 | 0 | 0 | 0 | 0 | 0 | 0 | 0 | 0 | 0 | 1 | 25 | 0 | 0
Parachute Body Type A | 36 | 1 | 36 | 0 | 0 | 0 | 0 | 0 | 0 | 1 | 36 | 0 | 0 | 0 | 0 | 0 | 0
Parachute Body Type D | 30 | 0 | 0 | 0 | 0 | 0 | 0 | 0 | 0 | 0 | 0 | 0 | 0 | 1 | 30 | 0 | 0
Parachute + Nose Cone Body Type B | 100 | 0 | 0 | 1 | 100 | 1 | 100 | 1 | 100 | 0 | 0 | 0 | 0 | 0 | 0 | 0 | 0
Parachute + Nose Cone Body Type C | 129 | 0 | 0 | 0 | 0 | 0 | 0 | 0 | 0 | 0 | 0 | 1 | 129 | 0 | 0 | 0 | 0
Nose Cone Ejection Hatch A/B/C | 123 | 0 | 0 | 1 | 123 | 1 | 123 | 1 | 123 | 0 | 0 | 0 | 0 | 0 | 0 | 0 | 0
Nose Cone Ejection Hatch + Adapter Ring | 110 | 0 | 0 | 0 | 0 | 0 | 0 | 0 | 0 | 0 | 0 | 1 | 110 | 0 | 0 | 0 | 0
Nose Cone Adapter Ring A/B/C | 26 | 0 | 0 | 1 | 26 | 1 | 26 | 1 | 26 | 0 | 0 | 0 | 0 | 0 | 0 | 0 | 0
Fins Type 1 | 15 | 0 | 0 | 3 | 45 | 3 | 45 | 3 | 45 | 0 | 0 | 1 | 15 | 1 | 15 | 1 | 15
Fins Ring Type 1 | 5 | 0 | 0 | 2 | 10 | 2 | 10 | 2 | 10 | 0 | 0 | 1 | 5 | 1 | 5 | 1 | 5
Fins Type 2 | 35 | 0 | 0 | 0 | 0 | 0 | 0 | 0 | 0 | 0 | 0 | 0 | 0 | 0 | 0 | 0 | 0
Fins Ring Type 2 | 9 | 0 | 0 | 0 | 0 | 0 | 0 | 0 | 0 | 0 | 0 | 0 | 0 | 0 | 0 | 0 | 0
Misc (Cords) | 25 | 0 | 0 | 1 | 25 | 1 | 25 | 1 | 25 | 0 | 0 | 0 | 0 | 0 | 0 | 0 | 0
 |  | 1.5 | 188 | 4.125 | 899 | 6.75 | 1005 | 9.375 | 1111 | 12 | 612 | 12 | 1019 | 12 | 825 | 12 | 899

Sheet: 3D-Parts
Part | Color | Use | Description | Remix
Fins Ring Type 1 Heavy | Light Purple | Fins | Customized Fin Ring
Fins Ring Type 1 Light | Light Purple | Fins | Customized Fin Ring half the height to save weight
Fin Type 1 A | Dark Purple | Fins | Orignal downloaded Fin corrected for size | https://www.thingiverse.com/thing:3642349
Fin Type 1 B | Light Purple | Fins | Orignal downloaded Fin corrected for size, shape Triangle
Fin Type 1 C | Light Purple | Fins | Orignal downloaded Fin corrected for size, shape Round
Fin Type 1 D | Light Purple | Fins | Orignal downloaded Fin corrected for size, shape Square
Fin Type 1 C Large | Light Purple | Fins | Orignal downloaded Fin corrected for size,shape Round, Large
Rail Guide Mount Foot | Red | Rail Guide Mount | Rail Guide Mount Foot to screw in base and slide in square rails
Rail Guide Mount Slider | Red | Rail Guide Mount | Rail Guide Mount Slider to slide the ring up and down in the rails
Rail Guide Mount Ring | Red | Rail Guide Mount | Rail Guide Mount Ring to hold body rocket straight
Hose Connector Compressed Air Pomp | Orange | Bottle & Nozzle & Hose Connectors | Hose Connector Compressed Air Pomp to transiation from default valve to hose
Bottle Connector | Orange | Bottle & Nozzle & Hose Connectors | Improved bottle connector where a o ring slides between the walls and where the bottle screws in
Valve Connector | Orange | Bottle & Nozzle & Hose Connectors | Improved bottle connector where a o ring slides between the walls and where the Air Pressure Quick release threads into
Servo Motor Arm Type 1 | Light Green | Servo Arms | Servo Motor Arm Type 1 where round arm is squared
Servo Motor Arm Type 2 | Light Green | Servo Arms | Servo Motor Arm Type 1 where round arm is squared en extended
Launch Platform Base Air pressure Quick release | Dark Green | Launching Platform Air Pressure Release | Customized Raketfuedrockets PodPad Launch Platform Base for Air pressure Quick release BSP Euro line | https://www.raketfuedrockets.com/en/3dprinting.htm#xl_PodPad
Launch Platform Foot | Dark Green | Launching Platform Air Pressure Release | PodPad Launch Platform Foot | https://www.raketfuedrockets.com/en/3dprinting.htm#xl_PodPad
Launch Platform Leg | Dark Green | Launching Platform Air Pressure Release | Launch Platform Leg
Launch Platform Air pressure Quick release Trigger | Dark Green | Launching Platform Air Pressure Release | Customized Raketfuedrockets PodPad Launch Platform Qucik Release for Air pressure BSP Euro line | https://www.raketfuedrockets.com/en/3dprinting.htm#xl_PodPad
Launch Platform Base Air pressure Cable Tie | Green | Launching Platform Cable Tie Release | Customized Raketfuedrockets PodPad Launch Platform Base for Air pressure Cable Tie | https://www.raketfuedrockets.com/en/3dprinting.htm#xl_PodPad
Launch Platform Air pressure Cable Tie Trigger | Green | Launching Platform Cable Tie Release | Standard Cable Tie Trigger | https://www.thingiverse.com/thing:2835346
Launch Platform Air pressure Cable Tie Holder | Green | Launching Platform Cable Tie Release | Standard Cable Tie Holder | https://www.thingiverse.com/thing:2835346
Launch Platform Air pressure Cable Tie Slider | Green | Launching Platform Cable Tie Release | Standard Cable Tie Slider | https://www.thingiverse.com/thing:2835346
Flight Computer Mount | Yellow | Payload Enclosure | Mount for ESP32 controller
Battery Mount | Yellow | Payload Enclosure | Mount for 3000 mAh Li-On Battery 7.4 V
Payload Bottle Connector Type B | Yellow | Payload Enclosure | Connector between top of bottle and and Payload Body
Payload Body | Yellow | Payload Enclosure | Payload body with small rails to mount ESP and Battery
Payload Nose Connector | Yellow | Payload Enclosure | Connector between top of the Payload Body and the Nose
Nose Cone Tip | Blue | Parachute Ejection Module | Nose Cone Tip of the parachute eject system | https://www.thingiverse.com/thing:4564390
Nose Cone Body Type B | Blue | Parachute Ejection Module | Nose Cone Body of the parachute eject system that slides over body | https://www.thingiverse.com/thing:4564390
Nose Cone Ejection Hatch | Blue | Parachute Ejection Module | Nose Cone Ejection hach of the parachute eject system | https://www.thingiverse.com/thing:4564390
Payload Bottle Connector Type A | Gray | Simple Rocket & Parachute Module | Connector between top of bottle and and Parachute Body | https://www.thingiverse.com/thing:294758
Nose Cone Body Type A | Gray | Simple Rocket & Parachute Module | Nose Cone Body of the parachute eject system that connects to Payload Bottle Connector Type A | https://www.thingiverse.com/thing:294758
Parachute Mechanical Trigger Part 1 | Gray | Simple Rocket & Parachute Module | Parachute Mechanical Trigger Part Square | https://www.thingiverse.com/thing:294758
Parachute Mechanical Trigger Part 2 | Gray | Simple Rocket & Parachute Module | Parachute Mechanical Trigger Part Stick | https://www.thingiverse.com/thing:294758

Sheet: Misc-Parts
Part | Amount | Use | Description
Rail Guide Square Bar | 1 | Rail Guide Mount | Square Rail Guide bar of 22mm x 22mm
Hose for air | 1 | Bottle & Nozzle & Hose Connectors | Garden hose that is rated for 12 bar
Hose for water | 1 | Bottle & Nozzle & Hose Connectors | Garden hose
Two-way valve | 1 | Bottle & Nozzle & Hose Connectors | GEKA Plus Two-way valve with internal thread MS G 3/4"
Hose connectors to | 3 | Bottle & Nozzle & Hose Connectors | FOR_Q Hose connector, 1/2" and 5/8"
Air Pressure Quick Release | 1 | Bottle & Nozzle & Hose Connectors | 1/4 "BSP Euro Air Line-connector female fitting internal thread
Air Pressure Quick Release Fitting | 1 | Bottle & Nozzle & Hose Connectors | 1/4 "BSP Euro Air Line-connector male fitting with BSP female thread

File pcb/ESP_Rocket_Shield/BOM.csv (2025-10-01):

Ref | Value | Symbol | Notes
U1 | L7805 | Regulator_Linear:L7805 | TO-220 or TO-252
F1 | 2A Resettable Fuse | Device:Polyfuse | 1206
D1 | SS14 Schottky | Device:D_Schottky | SMA
U2 | BMP280 | Sensor_Pressure:BMP280 | Use BMP388/DPS310 if preferred
U3 | MPU6050 | Sensor_Motion:MPU-6050 | Use ICM-42688-P if preferred
R_SDA | 4.7k | Device:R | Pull-up to 3V3
R_SCL | 4.7k | Device:R | Pull-up to 3V3
R5 | 330 | Device:R | Series on LED data
CIN1 | 10uF | Device:C | Input to L7805
CIN2 | 100nF | Device:C | Input to L7805
COUT1 | 10uF | Device:C | Output of L7805
COUT2 | 100nF | Device:C | Output of L7805
C_LED | 470uF | Device:CP | Across LED pads
Q1 | 2N7002 | Device:Q_NMOS_GSD | or MMBT2222A NPN
R4 | 1k | Device:R | Gate/Base resistor
BZ1 | Active 5V Buzzer | Buzzer_Beeper:MagneticBuzzer | 12mm THT recommended
J1 | Conn_01x02 | Connector_Generic:Conn_01x02 | Battery IN
J2 | Conn_01x19 | Connector_Generic:Conn_01x19 | ESP32-S3 left header
J3 | Conn_01x19 | Connector_Generic:Conn_01x19 | ESP32-S3 right header
J4 | Conn_01x03 | Connector_Generic:Conn_01x03 | LED OUT (+5V/Data/GND)
J5 | Conn_01x03 | Connector_Generic:Conn_01x03 | Servo (+5V/PWM/GND)

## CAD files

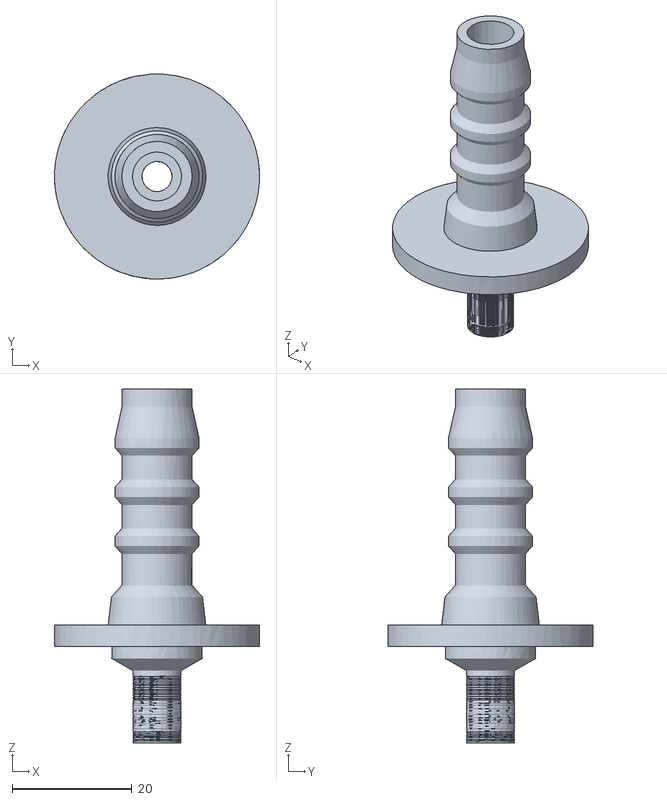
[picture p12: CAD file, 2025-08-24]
3d-designs/Hose Connector Compressed Air Pomp.stl
34.2 x 34.2 x 59.0

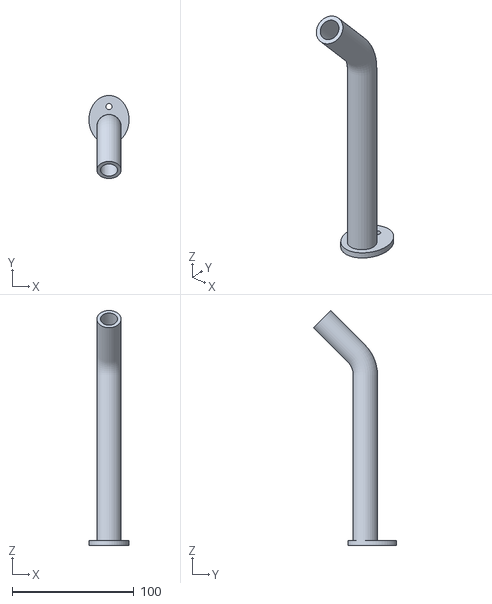
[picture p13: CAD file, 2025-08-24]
3d-designs/Launch Platform Leg.stl
33.0 x 68.3 x 193.0

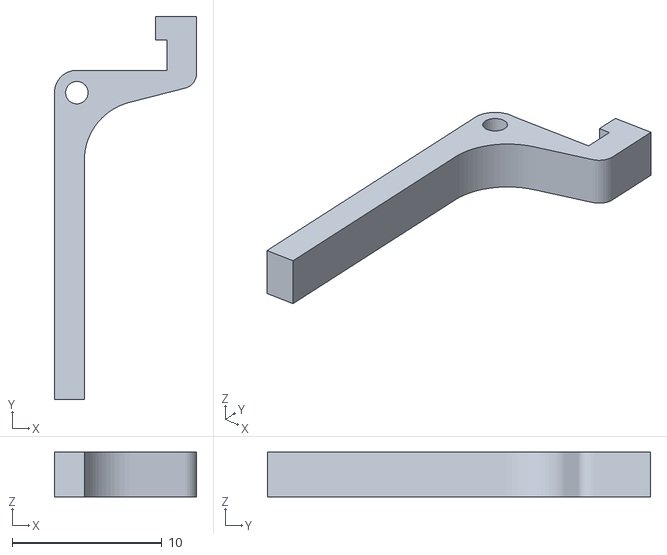
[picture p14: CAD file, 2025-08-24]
3d-designs/Parachute Mechanical Trigger Part 2.stl
9.50 x 25.6 x 3.00

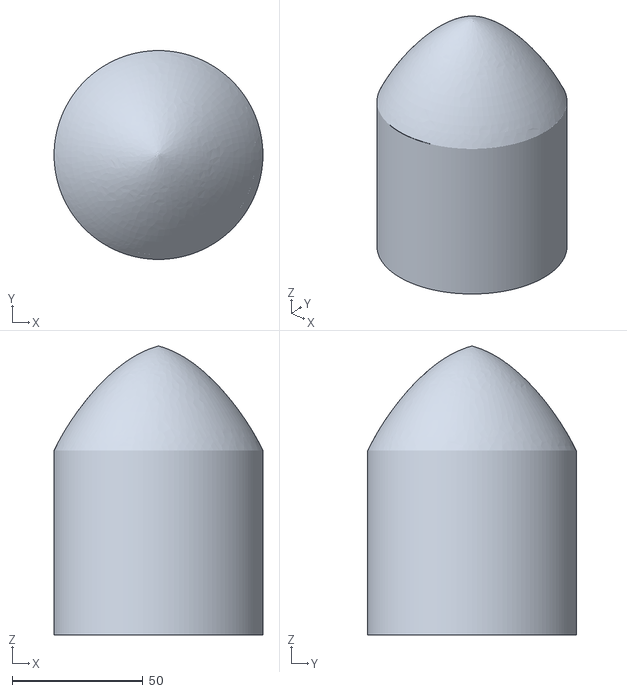
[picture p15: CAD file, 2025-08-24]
3d-designs/Nose Cone Body Type A.stl
79.9 x 79.9 x 110.5

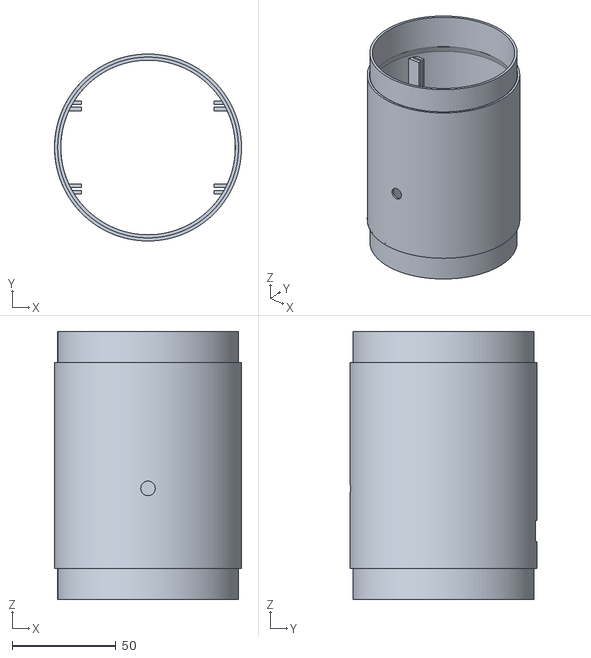
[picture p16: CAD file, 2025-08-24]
3d-designs/Payload Body.stl
90.0 x 90.0 x 129.0

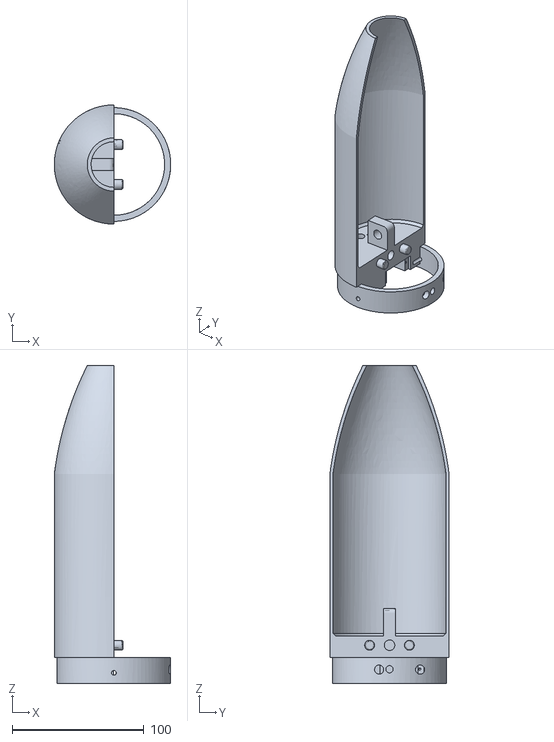
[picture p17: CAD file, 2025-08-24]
3d-designs/Nose Cone Body Type B.stl
88.6 x 90.7 x 241.8

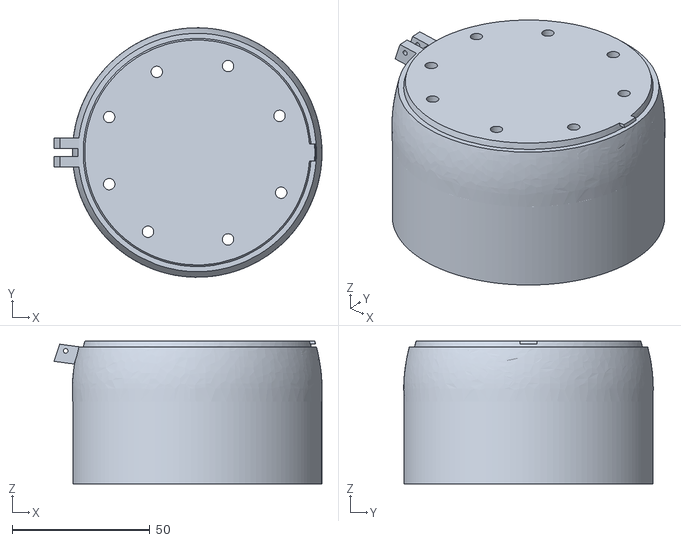
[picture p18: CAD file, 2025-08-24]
3d-designs/Payload Bottle Connector Type A.stl
97.4 x 90.7 x 51.9

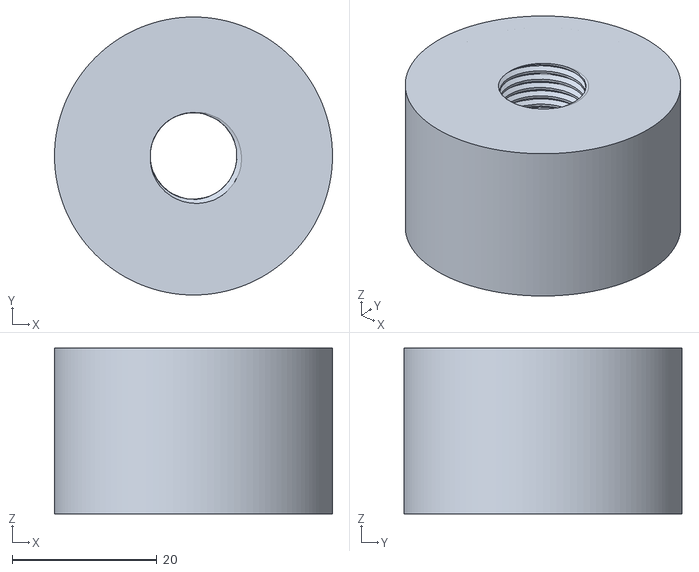
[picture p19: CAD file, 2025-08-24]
3d-designs/Valve Connector.stl
38.4 x 38.4 x 22.9

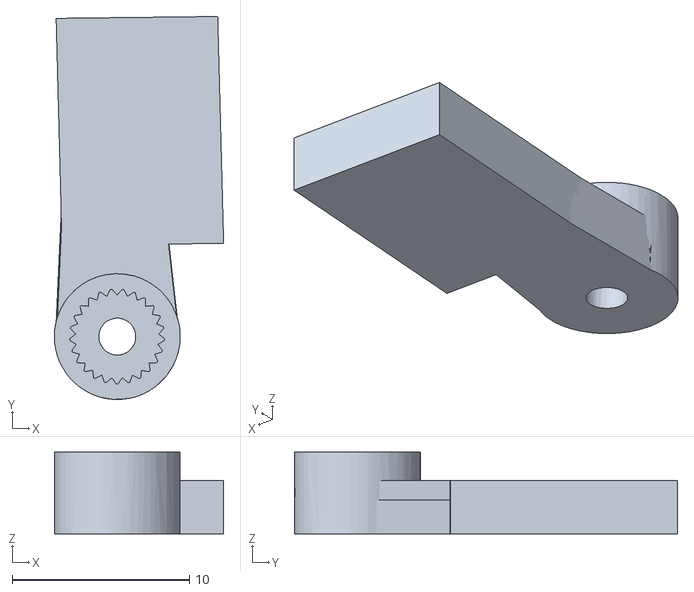
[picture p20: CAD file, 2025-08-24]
3d-designs/Servo Motor Arm Type 2.stl
9.55 x 21.6 x 4.60

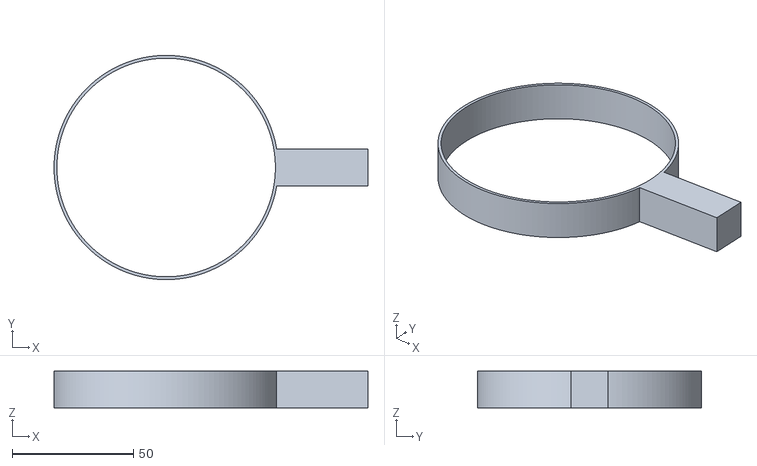
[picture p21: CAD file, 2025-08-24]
3d-designs/Rail Guide Mount Ring.stl
129.5 x 92.5 x 15.1

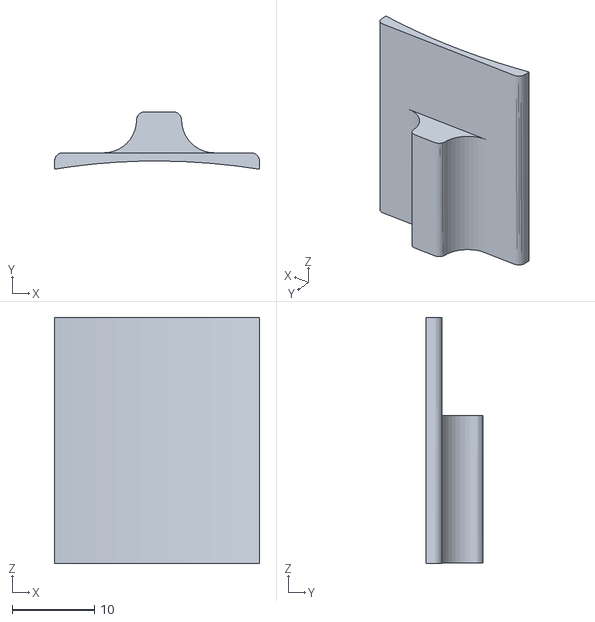
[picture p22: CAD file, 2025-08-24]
3d-designs/Parachute Mechanical Trigger Part 1.stl
25.0 x 7.00 x 30.0

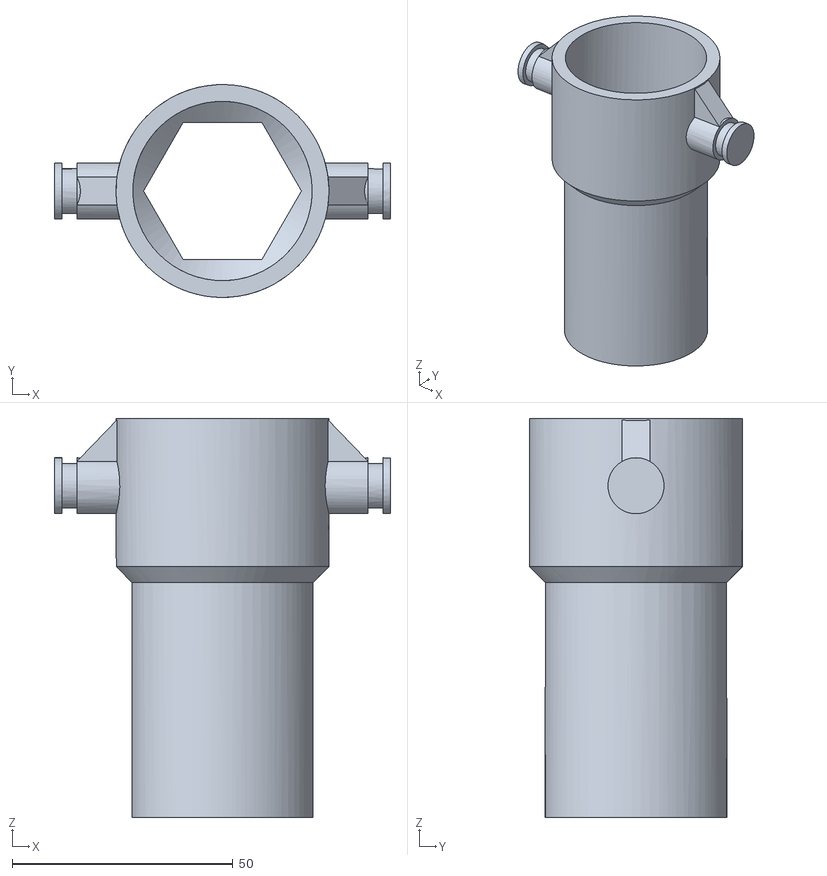
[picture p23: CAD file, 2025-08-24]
3d-designs/Launch Platform Air pressure Cable Tie Holder.stl
76.2 x 48.3 x 90.4

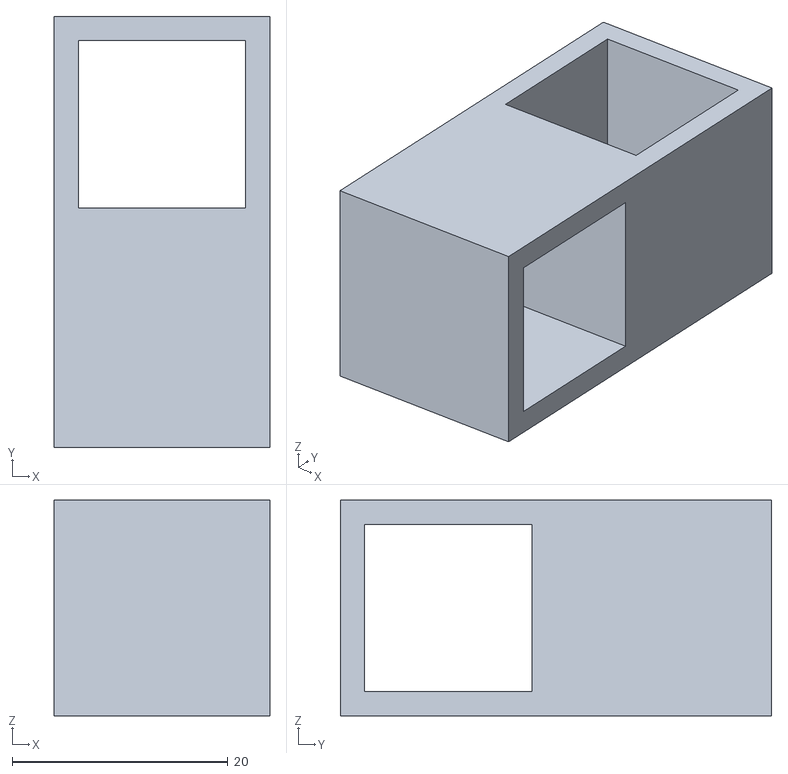
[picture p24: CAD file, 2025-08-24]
3d-designs/Rail Guide Mount Slider.stl
20.0 x 40.0 x 20.0

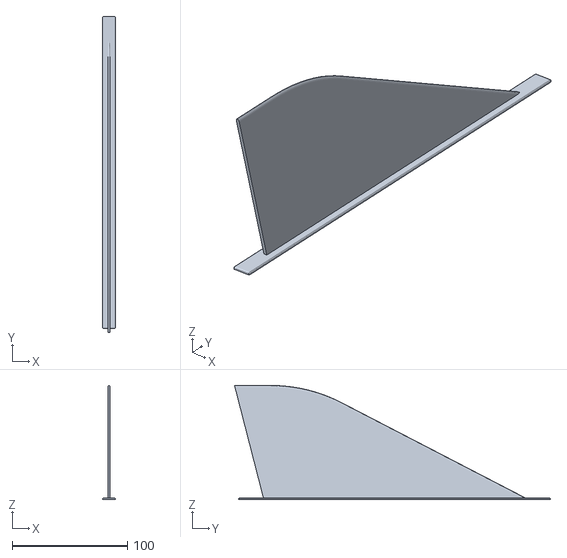
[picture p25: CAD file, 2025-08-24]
3d-designs/Fin Type 1 C Large.stl
11.1 x 274.0 x 99.0

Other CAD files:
3d-designs/Launch Platform Base Air pressure Quick release.stl
3d-designs/Fins Ring Type 1 Heavy.stl
3d-designs/Nose Cone Ejection Hatch.stl
3d-designs/Fin Type 1 B.stl
3d-designs/Battery Mount.stl
3d-designs/Bottle Connector.stl
3d-designs/Fin Type 1 A.stl
3d-designs/Fin Type 1 C.stl
3d-designs/Fin Type 1 D.stl
3d-designs/Fins Ring Type 1 Light.stl
3d-designs/Flight Computer Mount.stl
3d-designs/Launch Platform Air pressure Cable Tie Slider.stl
3d-designs/Launch Platform Air pressure Cable Tie Trigger.stl
3d-designs/Launch Platform Air pressure Quick release Trigger.stl
3d-designs/Launch Platform Base Air pressure Cable Tie.stl
3d-designs/Launch Platform Foot.stl
3d-designs/Nose Cone Tip.stl
3d-designs/Payload Bottle Connector Type B.stl
3d-designs/Payload Nose Connector.stl
3d-designs/Rail Guide Mount Foot.stl
3d-designs/Servo Motor Arm Type 1.stl

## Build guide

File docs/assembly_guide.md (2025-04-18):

# Assembly Guide for ESP Controlled Rocket

This guide provides detailed instructions to help you assemble your ESP Controlled Rocket from printed parts and electronic components. Follow each section carefully to ensure a successful build.

*(Note: The design files for all 3D printed components are still in development and will be released soon.)*

## Table of Contents

- [Introduction](#introduction)  
- [Pre-Assembly Checklist](#pre-assembly-checklist)  
- [3D Printing the Components](#3d-printing-the-components)  
- [Hardware Components Overview](#hardware-components-overview)  
- [Wiring and Electronics Integration](#wiring-and-electronics-integration)  
- [Mechanical Assembly](#mechanical-assembly)  
- [Final Assembly and Testing](#final-assembly-and-testing)  
- [Troubleshooting](#troubleshooting)  
- [Additional Resources](#additional-resources)

---

## Introduction

The ESP Controlled Rocket combines a custom flight computer with carefully designed 3D printed parts to create a robust rocket system. This guide outlines each step of the assembly process—from printing the parts to integrating the electronics and performing final tests.

## Pre-Assembly Checklist

Before beginning assembly, ensure you have:

- **3D Printed Parts:** *(STL files coming soon)*  
  - Rocket Body  
  - Nose Cone  
  - Fins  
  - Mounting Brackets  
- **Electronics:**  
  - ESP32 (SD_MMC support)  
  - BMP280 & MPU6050 Sensors  
  - Servo Motor  
  - SD Card Module  
  - Wiring & Connectors  
- **Tools:**  
  - 3D Printer (PLA recommended)  
  - Soldering Iron  
  - Screwdrivers  
  - Multimeter  
- **Software:**  
  - Arduino IDE / PlatformIO  
  - Repository code & docs

*(Camera module removed as of v3.3.0.)*

## 3D Printing the Components

1. **STL Files:** in `3D_Designs` folder (coming soon)  
2. **Print Settings:**  
   - PLA, 0.2 mm layer, 20–30% infill  
   - Supports as needed  
3. **Post-Processing:**  
   - Remove supports, sand edges, test-fit

## Hardware Components Overview

- **ESP32**  
- **BMP280 & MPU6050**  
- **Servo Motor**  
- **SD Card Module**  
- **Cables & Connectors**

## Wiring and Electronics Integration

1. **Sensors (I2C):**  
   - BMP280: SDA → GPIO 42, SCL → GPIO 37  
   - MPU6050: SDA/SCL on separate I2C bus if available  
2. **Servo:** Signal → GPIO 14, Power → 5 V, GND → common  
3. **SD Card (SD_MMC):**  
   - CMD → GPIO 38, CLK → GPIO 39, D0 → GPIO 40  
4. **Power:** Stable 3.3 V/5 V supply, common ground  

*See [Wiring Diagram](wiring_diagram.md) for visuals.*

## Mechanical Assembly

1. **Rocket Body:** Join printed parts, align compartments  
2. **Mount Electronics:** Secure ESP32 & sensors in brackets  
3. **Parachute Mechanism:** Mount servo and release latch  
4. **Final Integration:** Attach nose cone & fins, ensure rigidity

## Final Assembly and Testing

1. **Pre-Flight Check:** Verify wiring, mounts, sensors  
2. **Power On & Diagnostics:** Upload firmware, monitor serial  
3. **Ground Testing:** Arm/release parachute, check telemetry  
4. **Final Assembly:** Close compartments, insert SD card

## Troubleshooting

- **Sensor Issues:** Check I2C wiring & axis config  
- **WiFi/OTA:** Verify credentials & AP mode  
- **SD Card:** FAT32 format & proper wiring  
- **Servo:** Test separately & ensure power

*(Camera/timelapse removed.)*

## Additional Resources

- [Flight Computer Docs](flight_computer.md)  
- [Wiring Diagram](wiring_diagram.md)

*Happy building!*

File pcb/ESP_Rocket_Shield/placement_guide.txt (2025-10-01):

Placement Guide (suggested):
- Power section (J1, F1, D1, U1, big caps) along LEFT edge for airflow and heatsinking.
- ESP32 female headers centered; ensure clearance for USB and buttons on the dev board.
- Sensors (U2 baro, U3 IMU) in the middle; keep-out for high current/noise; add vent hole under baro.
- Buzzer (BZ1) on RIGHT edge, away from sensors; keep return path tight.
- LED pads (J4) near a board edge with 330R (R5) placed at the edge; large electrolytic (C_LED) next to pads.
- Servo header (J5) at an accessible edge.
- Mounting holes at four corners are included in PCB Edge.Cuts; adjust for your airframe.

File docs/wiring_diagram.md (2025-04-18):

# Wiring Diagram (v3.4.0)

*Reflects version 3.4.0: camera removed, RGB LED ring added.*

[![](https://mermaid.ink/img/pako:eNp1VG1vmzAQ_isnS_tGMiAEApoqJZCmL2FCo9uHkalywUnQwI6MaddV_e-zDQ1po32IdC_Pc_fc-cILyllBUIC2FXvK95gLuIs2FODTJ1gwzAvAtICEPRGuok37sOP4sO9yKgIw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)](https://mermaid.live/edit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)

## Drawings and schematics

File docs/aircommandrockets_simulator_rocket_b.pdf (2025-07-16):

# Water Rocket Simulator

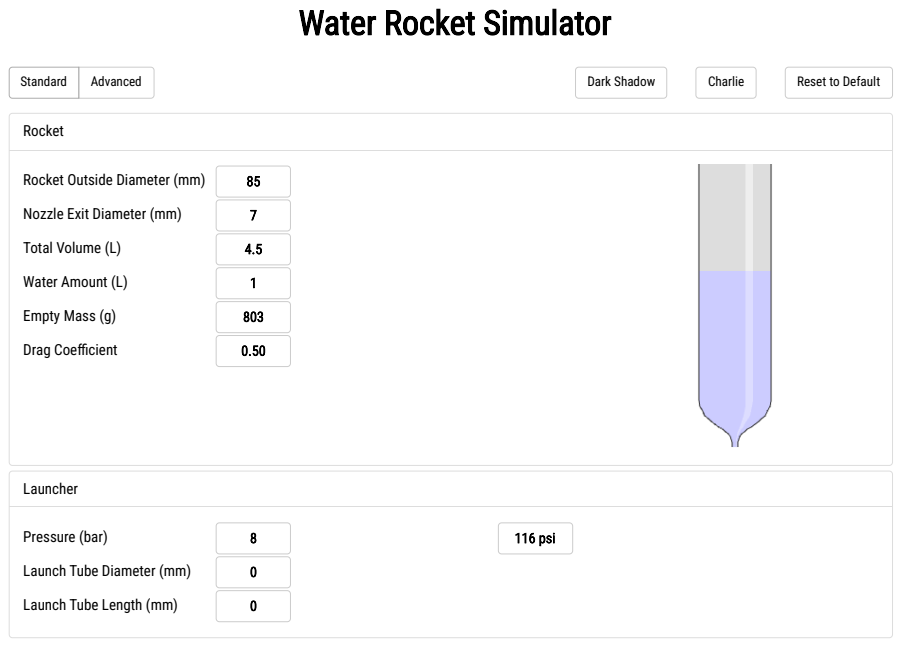
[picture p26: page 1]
Rocket; Launcher; Pressure (bar); 116 psi; Launch Tube Diameter (mm); Launch Tube Length (mm); Advanced; Dark Shadow; Charlie; Reset to Default; Rocket Outside Diameter (mm); Nozzle Exit Diameter (mm); Total Volume (L); Water Amount (L); Empty Mass (g); Drag Coecient; Standard

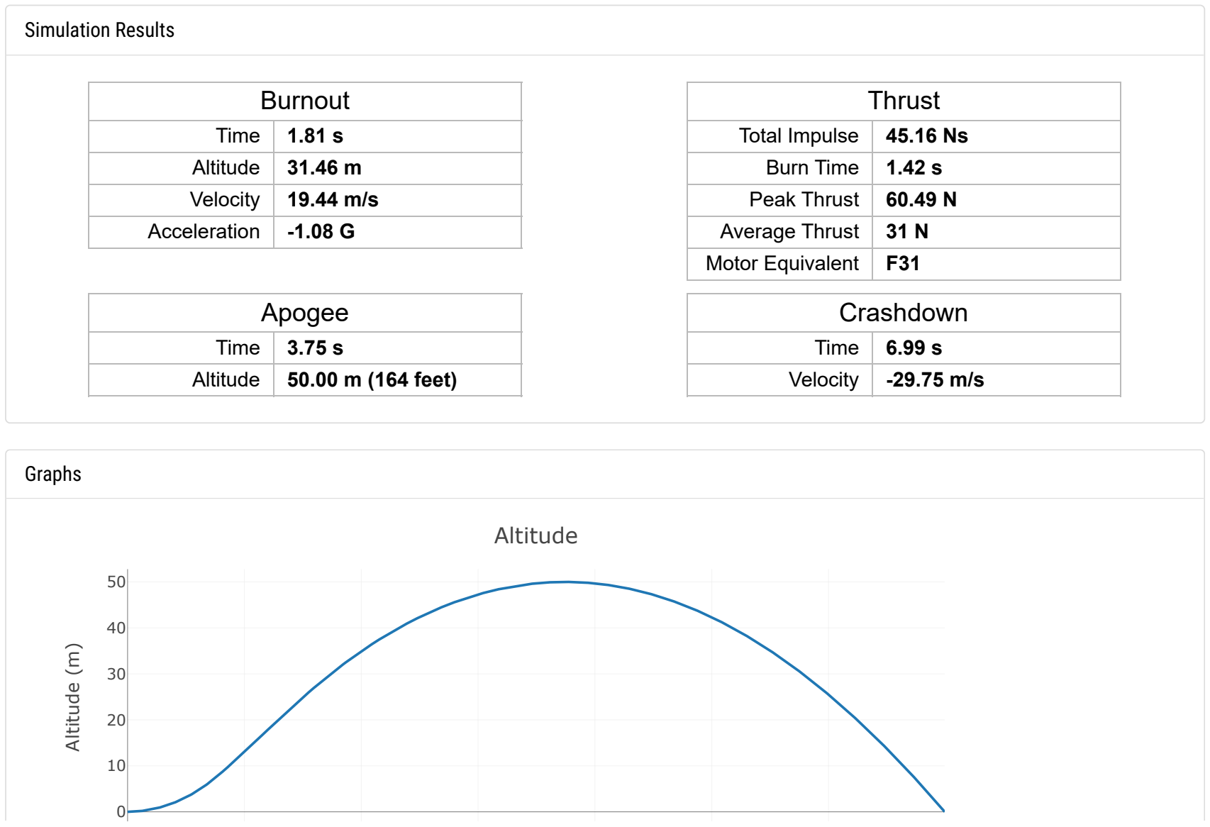
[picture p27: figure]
Simulation Results; Graphs; Burnout; Time; Altitude; Velocity; Acceleration; Thrust; Total Impulse; Burn Time; Peak Thrust; Average Thrust; Motor Equivalent; Apogee; 50.00 m (164 feet); Crashdown; Altitude (m)

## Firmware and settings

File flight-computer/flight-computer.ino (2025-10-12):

/*
 * Flight Computer Firmware for ESP32 – Version 3.8.0
 *
 * ─────────────────────────────────────────────────────────────
 *  What’s new since 3.7.0 (Dashboard & SPIFFS File Manager):
 *
 *  ✦ Improved Height Determination:
 *    - Refined altitude calculation with better noise filtering and apogee logic.
 *    - Vertical speed derived directly from filtered altitude data.
 *
 *  ✦ New Sensors & Telemetry Fields:
 *    - Vertical Speed (m/s): Real-time rate of ascent/descent.
 *    - Apogee Detected: Flags when peak altitude is reached.
 *    - Apogee Altitude: Highest altitude recorded.
 *    - Rocket Status: Displays current flight phase (Idle, Launch, Coast, Descent, Landed).
 *    - Triggered By: Logs the condition that activated parachute deployment.
 *    - Launch Acc Threshold: Minimum acceleration to confirm launch.
 *    - Min Apogee Altitude: Prevents false apogee triggers at low altitude.
 *    - Neg VS Confirm: Requires negative vertical speed to validate apogee.
 *    - Neg Samples Confirm: Ensures multiple samples confirm descent.
 *    - Ground Settle (ms): Stabilization delay before calibration at startup.
 *
 *  ✦ Data Handling & Reliability:
 *    - Automatic SPIFFS-to-SD copy when internal storage is full.
 *    - Fixed SD log download function.
 *    - Added “Delete All” option for SD card cleanup.
 *
 *  ✦ General:
 *    - Improved system stability and synchronization with dashboard.
 *    - Enhanced recovery from calibration and sensor restarts.
 *
 *  Release Date: October 2025
 *
 * ┌───────────────────────────────────────────────┐
 * │                  Endpoints Overview           │
 * └───────────────────────────────────────────────┘
 *
 * ───── HTTP REST API & Static Content ──────────────
 *  GET   /                  → Redirects to /index.html, sets flight mode
 *  GET   /visualization     → Redirects to visualization UI, sets visualization mode
 *  GET   /visualization/    → Serves static visualization files from SPIFFS
 *  GET   /listfiles          → Lists files on SD & SPIFFS (JSON)
 *  GET   /files             → Redirect to UI for files on SD & SPIFFS
 *  GET   /deleteFile        → Delete file from SD or SPIFFS (param: name)
 *  GET   /deleteFileSPIFFS  → Delete file from SPIFFS (param: name)
 *  GET   /deleteFileSD      → Delete file from SD card (param: name)
 *  GET   /downloadFile      → Download file from SD, fallback to SPIFFS (param: name)
 *  POST  /upload            → Upload file to SPIFFS (multipart/form-data)
 *  POST  /uploadsd          → Upload file to SD card (multipart/form-data)
 *  GET   /spiffsupload      → HTML page for uploading files to SPIFFS (multi-file/folder support)
 *  POST  /spiffsupload      → Actual SPIFFS upload handler (uses folder argument)
 *  GET   /gyro              → Get gyroscope readings as JSON
 *  GET   /acc               → Get accelerometer readings as JSON
 *  GET   /temp              → Get temperature (plain text)
 *  GET   /reset             → Reset all gyro values to zero
 *  GET   /resetX|/resetY|/resetZ → Reset specific gyro axis to zero
 *  GET   /index.html, /style.css, /script.js, /visualization/* → Serve static files from SPIFFS
 *
 * ───── OTA Firmware Update ──────────────
 *  POST  /update            → Firmware update via ESP32 HTTPUpdateServer (auto-registered)
 *
 * ───── WebSocket (port 81) ──────────────
 *  Handles:
 *      - Sensor and threshold settings (JSON keys: newThreshold, newAccX/Y/Z, enAltDrop/AccX/Y/Z, etc.)
 *      - Trigger logic selection (AND/OR)
 *      - Sensor calibration (calibrateSensors)
 *      - Parachute commands (Armed/Released/Unarmed)
 *      - Axis correction config (axisConfig)
 *      - Location update (latitude/longitude) triggers API pressure refresh and broadcasts new settings
 *      - Live telemetry/diagnostic broadcast to all clients
 *
 * ───── Outbound API Calls ──────────────
 *  - OpenWeatherMap API for live pressure calibration
 *
 * ───── Dashboard & LED Feedback Reference ──────────────
 *  • Color Wheel Indices (0–255 → RGB via strip.Wheel(index)):
 *      0   → red
 *     30   → orange
 *     85   → green
 *    125   → aqua
 *    170   → blue
 *    200   → purple
 *
 *  • Core LED Functions:
 *      setAllLEDs(color)
 *      blinkColor(color, times, delayms)
 *      showLEDColorsSequentially(color, direction, rotations)
 *      showRainbowCycle(wait, direction, rotations)
 *
 *  • Main LED Sequences & System States:
 *      Startup/Unarmed, Wi-Fi status, Parachute Armed/Released, Calibrate Sensors, Visualization Mode
 *
 *  • File Management, Upload/Download, and Warning Indicators:
 *      File Manager, Delete File, Download File, Upload File, SPIFFS Storage Full
 *
 *  • Data Logging:
 *      – All data always logged to SD card if available
 *      – Data also logged to SPIFFS as long as there is enough free space
 *      – If SPIFFS free space drops below threshold, logging is suspended and visual warning shown
 *
 * For troubleshooting, see README and module docs.
 */

//
struct DelStats; // forward declaration so Arduino's auto-prototype knows the type

// -----------------------
// Library Inclusions
// -----------------------
#define sensor_t adafruit_sensor_t
#include <Adafruit_MPU6050.h>
#include <Adafruit_BMP280.h>
#undef sensor_t

#include <Wire.h>
#include <Adafruit_Sensor.h>
// #include <Adafruit_BMP280.h>
// #include <Adafruit_MPU6050.h>
#include <SD_MMC.h>
#include "sd_read_write.h"
#include <ESP32Servo.h>
#include <WiFi.h>
extern "C"
{
#include "esp_wifi.h" // For disabling WiFi power saving (esp_wifi_set_ps)
}
#include <WiFiUdp.h>
#include <NTPClient.h>
#include <WebServer.h>
#include <WebSocketsServer.h>
#include <ArduinoJson.h>
#include <HTTPClient.h>
#include <Arduino_ESP32_OTA.h>
#include <HTTPUpdateServer.h>
// #include <ESPmDNS.h>
#include <EEPROM.h>
#include <SPIFFS.h>
#include <math.h>
#include <vector>

// -----------------------
// LED Circle Setup (Freenove_WS2812)
// -----------------------
// #include "Freenove_WS2812_Lib_for_ESP32.h"
#include <Adafruit_NeoPixel.h>
#define LEDS_COUNT 39 // Number of LEDs in the strip
#define LEDS_PIN 17   // GPIO pin for the LED strip data line
#define CHANNEL 0     // PWM channel (if applicable)
// Freenove_ESP32_WS2812 strip = Freenove_ESP32_WS2812(LEDS_COUNT, LEDS_PIN, CHANNEL, TYPE_GRB);
Adafruit_NeoPixel strip(LEDS_COUNT, LEDS_PIN, NEO_GRB + NEO_KHZ800);

// -----------------------
// Macro Definitions & Global Variables
// -----------------------
#define EEPROM_SIZE 10                 // EEPROM size
#define EEPROM_PRESSURE_ADDR 0         // EEPROM address for storing pressure
const size_t MAX_SPIFFS_USED_KB = 700; // Set your preferred limit (in KB)
bool spiffsLoggingAllowed = false;
bool alreadyWarned = false;
bool apiSuccess = false;
bool debugSerial = false;        // Enable/disable serial debug printing
bool sensorModeFlight = true;    // true: Flight sensor mode; false: Visualization mode
int axisConfig = 5;              // 0 = default mapping, 1 = alternative mapping (or more states as needed)
bool sensorsCalibrated = false;  // true when calibrated
bool sensorsCalibWarned = false; // helper for one-time warning (optional)
bool triggerAbs = true;          // Trigger on both positive and negative acceleration by default
String lastTriggeredBy = "NotTriggered";
String uiTriggeredBy = "NotTriggered";
bool enAltDrop = true;
bool enAccX = true;
bool enAccY = false;
bool enAccZ = true;

bool enApogee = true;
// SD card storage info
uint64_t totalSpace;
uint64_t usedSpace;

// Pressure variables for sensor readings and logging
String PressureSource = "";
float lastLocalPressure = 1013.25;
bool apiPressureUpdated = false;
bool showSensorInitLog = true;
bool bmpFound = false;
bool mpuFound = false;

// -----------------------
// WiFi Credentials and Access Point settings
// -----------------------

const char *ssid = "TDGC-Rocket";
const char *wifiPassword = "Rocket2022!";
const char *apSSID = "RocketAP";
const char *apPassword = "Rocket2022!";

// -----------------------
// OpenWeatherMap API Settings (Anonymized)
// -----------------------
const char *openWeatherMapApiKey = "xxxxxx";  // Anonymized API key
float currentLatitude = 51.07741431;                              // Anonymized Latitude
float currentLongitude = 5.88510756;                              // Anonymized Longitude
const char *owmEndpoint = "https://api.openweathermap.org/data/3.0/onecall";

// -----------------------
// Time Setup using NTP
// -----------------------
#define UTC_OFFSET_IN_SECONDS 3600 // Offset for local time zone (1 hour)
WiFiUDP ntpUDP;
NTPClient timeClient(ntpUDP, "pool.ntp.org", UTC_OFFSET_IN_SECONDS);
unsigned long lastSuccessfulNTP = 0;
unsigned long lastSyncMillis = 0;

// -----------------------
// Trigger & Calibration Variables for Parachute Operation
// -----------------------
float altitudeDropThreshold = 0.8;
float accXThreshold = 8.0;
float accYThreshold = 8.0;
float accZThreshold = 8.0;
bool useAndLogic = false; // If true, all conditions must meet; if false, any condition triggers

// Baseline for altitude and parachute status variables
float baselineAltitude = 0;
bool baselineCaptured = false;

// --- Altitude filtering & apogee detection additions ---
float ALT_EWMA_ALPHA = 0.20f;
float filteredRelAlt = 0.0f;
float prevFilteredRelAlt = 0.0f;
float verticalSpeed = 0.0f; // m/s
unsigned long lastAltUpdateMs = 0;

bool apogeeDetected = false;
float apogeeAltitude = 0.0f;
unsigned long apogeeMillis = 0;
int negVsCount = 0;

float MIN_ALTITUDE_FOR_APOGEE = 5.0f; // meters (tune)
float NEG_VS_CONFIRM = -0.20f;        // m/s (tune)
int NEG_COUNT_CONFIRM = 3;            // consecutive samples (tune)

float LAUNCH_ACC_THRESHOLD = 15.0f; // m/s^2 (tune)
unsigned long groundCandidateSince = 0;
unsigned long GROUND_SETTLE_MS = 2000;
String parachuteStatus = "unarmed";
String rocketStatus = "On Launchpad";
String parachutePreStatus = "unknown";

// Logging extremes for altitude values
float maxAbsoluteAltitude = -1000000.0;
float minAbsoluteAltitude = 1000000.0;
float maxRelativeAltitude = -1000000.0;
float minRelativeAltitude = 1000000.0;
float maxAltitudeDrop = -1000000.0;
float minAltitudeDrop = 1000000.0;
float armedMaxRelativeAltitude = 0;

// Accelerometer calibration offsets
float accXOffset = 0, accYOffset = 0, accZOffset = 0;

// -----------------------
// LED Color Global Variables (will be initialized later)
// -----------------------
uint32_t redColor, blueColor, purpleColor, greenColor, aquaColor, orangeColor;

// -----------------------
// Sensor & Servo Instances
// -----------------------
Adafruit_BMP280 bmp;  // BMP280 sensor instance
Adafruit_MPU6050 mpu; // MPU6050 sensor instance
Servo parachuteservo; // Servo controlling the parachute deployment
int servoPin = 14;    // Servo control pin

// Eén bron van waarheid voor de CSV-header
const char *CSV_HEADER_LINE =
    "Timestamp,BMP Temp,Pressure,Absolute Altitude,Relative Altitude,Altitude Drop,MPU Temp,RawAccX,RawAccY,RawAccZ,AccX_Calib,AccY_Calib,AccZ_Calib,GyroX,GyroY,GyroZ,Parachute Status,Local Pressure,Default Sea-Level Pressure,API Status,Max Abs Altitude,Min Abs Altitude,Max Rel Altitude,Min Rel Altitude,Max Alt Drop,Min Alt Drop,Total Space,Used Space,SPIFFS Total,SPIFFS Used,Latitude,Longitude,AltDropThres,AccXThres,AccYThres,AccZThres,TriggerLogic,AxisConfig,TriggeredBy,EnAltDrop,EnAccX,EnAccY,EnAccZ,Vertical Speed,RocketStatus,ApogeeDetected,ApogeeAltitude,EnApogee";

// -----------------------
// Web Server & OTA Instances
// -----------------------
WebServer server(80);
WebSocketsServer webSocket(81);
HTTPUpdateServer httpUpdater;

// -----------------------
// I2C Bus & SD_MMC Pin Definitions
// -----------------------
#define SDA_1 42
#define SCL_1 37
#define SD_MMC_CMD 38
#define SD_MMC_CLK 39
#define SD_MMC_D0 40

// -----------------------
// NEW FEATURE CODE GLOBALS (For visualization updates and gyro calibration)
// -----------------------
// Gyroscope sensor deviation values
float gyroX = 0.0, gyroY = 0.0, gyroZ = 0.0;
const float gyroXerror = 0.03;
const float gyroYerror = 0.03;
const float gyroZerror = 0.03;
File uploadFile; // Global handle for file uploads

// -----------------------
// WebSocket timing variables for Visualization updates
// -----------------------
unsigned long lastTimeGyro = 0;
unsigned long lastTimeAcc = 0;
unsigned long lastTimeTemperature = 0;
const unsigned long gyroDelay = 10;
const unsigned long accelerometerDelay = 200;
const unsigned long temperatureDelay = 1000;

// ---------------------------------------------------------------------------
// Small SPIFF uploader
// ---------------------------------------------------------------------------

const char spiffsUploaderHTML[] PROGMEM = R"rawliteral(
<!DOCTYPE html>
<html>
<head>
  <meta charset="utf-8" />
  <title>SPIFFS Uploader</title>
  <style>
    body { font-family:sans-serif; margin:30px; }
    h2 { color:#333; }
    .msg { margin:10px 0 15px 0; color: green;}
    input[type=file], input[type=text], button { font-size:1em; margin:5px 0; }
  </style>
</head>
<body>
  <div style="margin-bottom:20px;text-align:center;">
    <a href="/files"><button type="button">← Back to File Manager</button></a>
  </div>
  <h2>ESP32 SPIFFS File Uploader</h2>
  <form id="uploadForm" enctype="multipart/form-data" method="POST">
    <label>SPIFFS Folder (start with /):</label><br>
    <input type="text" id="folder" name="folder" value="/" size="30" required /><br>
    <label>Select file(s):</label><br>
    <input type="file" id="files" name="files" multiple required /><br>
    <button type="submit">Upload</button>
  </form>
  <div class="msg" id="result"></div>
  <script>
document.getElementById('uploadForm').onsubmit = async function(e) {
  e.preventDefault();
  var folder = document.getElementById('folder').value;
  var files = document.getElementById('files').files;
  if(!folder.startsWith('/')) { alert('Folder must start with /'); return false; }
  if(files.length === 0) { alert('Select at least one file!'); return false; }
  let results = [];
  for(let i=0; i<files.length; i++) {
    let formData = new FormData();
    formData.append('folder', folder);
    formData.append('file', files[i]);
    try {
      let res = await fetch('/spiffsupload', {method:'POST', body:formData});
      let txt = await res.text();
      results.push(folder + files[i].name + ': ' + txt);
    } catch (err) {
      results.push(folder + files[i].name + ': Error - ' + err);
    }
  }
  document.getElementById('result').innerHTML = results.join('<br>');
  return false;
}
  </script>
</body>
</html>
)rawliteral";
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
void loop()
{
  server.handleClient();
  webSocket.loop();

  // Update pressure from API if needed
  if (WiFi.status() == WL_CONNECTED)
  {
    if (!apiPressureUpdated)
      updatePressureFromAPI();
  }
  else
  {
    apiPressureUpdated = false;
  }

  // Update SD and SPIFFS stats
  totalSpace = SD_MMC.totalBytes() / (1024 * 1024);
  usedSpace = SD_MMC.usedBytes() / (1024 * 1024);
  size_t spiffsTotal = SPIFFS.totalBytes() / 1024;
  size_t spiffsUsed = SPIFFS.usedBytes() / 1024;

  // Sensor reads
  float bmpTemp = bmp.readTemperature();
  float pressure = bmp.readPressure() / 100.0F;
  float absoluteAltitude = bmp.readAltitude(getLocalSeaLevelPressure());
  sensors_event_t a, g, temp;
  mpu.getEvent(&a, &g, &temp);

  // Axis correction + calibration
  float corrAx, corrAy, corrAz;
  correctAxes(a.acceleration.x, a.acceleration.y, a.acceleration.z, corrAx, corrAy, corrAz);
  float relAccX = corrAx - accXOffset;
  float relAccY = corrAy - accYOffset;
  float relAccZ = corrAz - accZOffset;

  // Raw readings
  float rawAccX = a.acceleration.x;
  float rawAccY = a.acceleration.y;
  float rawAccZ = a.acceleration.z;

  // Altitude & drops

  float relativeAltitude = (parachuteStatus == "unarmed") ? 0 : absoluteAltitude - baselineAltitude;
  // --- Filtered altitude + vertical speed ---
  unsigned long _nowAltMs = millis();
  if (lastAltUpdateMs == 0)
  {
    filteredRelAlt = relativeAltitude;
    prevFilteredRelAlt = relativeAltitude;
    lastAltUpdateMs = _nowAltMs;
  }
  float _dt = (_nowAltMs - lastAltUpdateMs) / 1000.0f;
  if (_dt <= 0.0f)
    _dt = 0.001f;
  filteredRelAlt = ALT_EWMA_ALPHA * relativeAltitude + (1.0f - ALT_EWMA_ALPHA) * filteredRelAlt;
  verticalSpeed = (filteredRelAlt - prevFilteredRelAlt) / _dt;
  prevFilteredRelAlt = filteredRelAlt;
  lastAltUpdateMs = _nowAltMs;

  if (absoluteAltitude > maxAbsoluteAltitude)
    maxAbsoluteAltitude = absoluteAltitude;
  if (absoluteAltitude < minAbsoluteAltitude)
    minAbsoluteAltitude = absoluteAltitude;
  if (relativeAltitude > maxRelativeAltitude)
    maxRelativeAltitude = relativeAltitude;
  if (relativeAltitude < minRelativeAltitude)
    minRelativeAltitude = relativeAltitude;
  float altitudeDrop = (parachuteStatus == "armed") ? armedMaxRelativeAltitude - relativeAltitude : maxRelativeAltitude - relativeAltitude;
  if (altitudeDrop > maxAltitudeDrop)
    maxAltitudeDrop = altitudeDrop;
  if (altitudeDrop < minAltitudeDrop)
    minAltitudeDrop = altitudeDrop;

  // --- Rocket status & apogee detection ---
  // Launch detection (use Z-up calibrated acceleration)
  if (rocketStatus == "On Launchpad" && relAccZ > LAUNCH_ACC_THRESHOLD)
  {
    rocketStatus = "Launched";
    apogeeDetected = false;
    apogeeAltitude = 0.0f;
    negVsCount = 0;
  }

  // Apogee detection (requires sufficient altitude and sustained negative vertical speed)
  if (!apogeeDetected && filteredRelAlt > MIN_ALTITUDE_FOR_APOGEE)
  {
    if (verticalSpeed < NEG_VS_CONFIRM)
    {
      negVsCount++;
      if (negVsCount >= NEG_COUNT_CONFIRM)
      {
        apogeeDetected = true;
        apogeeAltitude = filteredRelAlt;
        apogeeMillis = millis();
        rocketStatus = "Max Apogee";
      }
    }
    else
    {
      if (negVsCount > 0)
        negVsCount--;
    }
  }

  // Alleen “On Ground” toestaan ná daadwerkelijke vlucht
  bool wasInFlight = (rocketStatus == "Launched" || rocketStatus == "Max Apogee");
  if (wasInFlight && fabs(filteredRelAlt) < 1.0f && fabs(verticalSpeed) < 0.05f)
  {
    if (groundCandidateSince == 0)
      groundCandidateSince = millis();
    else if (millis() - groundCandidateSince > GROUND_SETTLE_MS)
    {
      rocketStatus = "On Ground";
    }
  }
  else
  {
    groundCandidateSince = 0;
  }

  // --- Trigger evaluatie & oorzaakvastlegging (vervangt het hele oude blok) ---
  uiTriggeredBy = lastTriggeredBy; // wat we aan de UI tonen

  if (parachuteStatus == "armed")
  {
    // Terwijl we armed zijn, is de default-weergave "NotTriggered" totdat iets triggert
    uiTriggeredBy = "NotTriggered";

    // Evaluate only enabled triggers
    const bool triggerAlt = enAltDrop ? (altitudeDrop >= altitudeDropThreshold) : false;
    const bool triggerAccX = enAccX ? (triggerAbs ? (fabs(relAccX) >= accXThreshold) : (relAccX >= accXThreshold)) : false;
    const bool triggerAccY = enAccY ? (triggerAbs ? (fabs(relAccY) >= accYThreshold) : (relAccY >= accYThreshold)) : false;
    const bool triggerAccZ = enAccZ ? (triggerAbs ? (fabs(relAccZ) >= accZThreshold) : (relAccZ >= accZThreshold)) : false;
    const bool triggerApogee = enApogee ? apogeeDetected : false;

    // AND/OR logica over alleen de ingeschakelde triggers
    const bool enabled[5] = {enAltDrop, enAccX, enAccY, enAccZ, enApogee};
    const bool fired[5] = {triggerAlt, triggerAccX, triggerAccY, triggerAccZ, triggerApogee};
    const bool anyEnabled = enabled[0] || enabled[1] || enabled[2] || enabled[3] || enabled[4];

    bool triggerCondition = false;
    if (anyEnabled)
    {
      if (useAndLogic)
      {
        triggerCondition = true;
        for (int i = 0; i < 5; i++)
        {
          if (enabled[i] && !fired[i])
          {
            triggerCondition = false;
            break;
          }
        }
      }
      else
      {
        for (int i = 0; i < 5; i++)
        {
          if (enabled[i] && fired[i])
          {
            triggerCondition = true;
            break;
          }
        }
      }
    }

    // Track what triggered
    if (triggerCondition)
    {
      String triggersList;
      if (triggerAlt)
        triggersList += "Threshold Altitude Drop,";
      if (triggerAccX)
        triggersList += "Threshold AccX,";
      if (triggerAccY)
        triggersList += "Threshold AccY,";
      if (triggerAccZ)
        triggersList += "Threshold AccZ,";
      if (triggerApogee)
        triggersList += "Apogee Descent,";
      if (triggersList.length() > 0)
        triggersList.remove(triggersList.length() - 1); // strip trailing comma
      lastTriggeredBy = triggersList;
      uiTriggeredBy = lastTriggeredBy;
      parachuteRelease(); // zet status → "released"
    }
  }
  else
  {
    // Niet-armed: blijf de laatst bekende oorzaak tonen (of NotTriggered als er geen is)
    uiTriggeredBy = lastTriggeredBy.length() ? lastTriggeredBy : "NotTriggered";
  }
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

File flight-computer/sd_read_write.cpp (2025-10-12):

#include "sd_read_write.h"
extern bool debugSerial;  // Declaration so the sub cpp file can use it.


// --- ADD THIS (boven gebruik) ---
bool copyFileFS(fs::FS &srcFS, const char *srcPath, fs::FS &dstFS, const char *dstPath) {
  File src = srcFS.open(srcPath, FILE_READ);
  if (!src) return false;

  File dst = dstFS.open(dstPath, FILE_WRITE);
  if (!dst) { src.close(); return false; }

  uint8_t buf[512];
  size_t n;
  while ((n = src.read(buf, sizeof(buf))) > 0) {
    if (dst.write(buf, n) != n) { src.close(); dst.close(); return false; }
  }
  dst.flush();
  src.close();
  dst.close();
  return true;
}



void listDir(fs::FS &fs, const char * dirname, uint8_t levels){
    Serial.printf("Listing directory: %s\n", dirname);

    File root = fs.open(dirname);
    if(!root){
        Serial.println("Failed to open directory");
        return;
    }
    if(!root.isDirectory()){
        Serial.println("Not a directory");
        return;
    }

    File file = root.openNextFile();
    while(file){
        if(file.isDirectory()){
            Serial.print("  DIR : ");
            Serial.println(file.name());
            if(levels){
                listDir(fs, file.path(), levels -1);
            }
        } else {
            Serial.print("  FILE: ");
            Serial.print(file.name());
            Serial.print("  SIZE: ");
            Serial.println(file.size());
        }
        file = root.openNextFile();
    }
}

void createDir(fs::FS &fs, const char * path){
    Serial.printf("Creating Dir: %s\n", path);
    if(fs.mkdir(path)){
        Serial.println("Dir created");
    } else {
        Serial.println("mkdir failed");
    }
}

void removeDir(fs::FS &fs, const char * path){
    Serial.printf("Removing Dir: %s\n", path);
    if(fs.rmdir(path)){
        Serial.println("Dir removed");
    } else {
        Serial.println("rmdir failed");
    }
}

void readFile(fs::FS &fs, const char * path){
    Serial.printf("Reading file: %s\n", path);

    File file = fs.open(path);
    if(!file){
        Serial.println("Failed to open file for reading");
        return;
    }

    Serial.print("Read from file: ");
    while(file.available()){
        Serial.write(file.read());
    }
}

void writeFile(fs::FS &fs, const char * path, const char * message){
    Serial.printf("Writing file: %s\n", path);

    File file = fs.open(path, FILE_WRITE);
    if(!file){
        Serial.println("Failed to open file for writing");
        return;
    }
    if(file.print(message)){
        Serial.println("File written");
    } else {
        Serial.println("Write failed");
    }
}

void appendFile(fs::FS &fs, const char * path, const char * message){
    if(debugSerial) {
    Serial.printf("Appending to file: %s\n", path);
    }
    File file = fs.open(path, FILE_APPEND);
    if(!file){
        Serial.println("Failed to open file for appending");
        return;
    }
    if(file.print(message)){
        if(debugSerial) {
        Serial.println("Message appended");
        }
    } else {
        Serial.println("Append failed");
    }
}

void renameFile(fs::FS &fs, const char * path1, const char * path2){
    Serial.printf("Renaming file %s to %s\n", path1, path2);
    if (fs.rename(path1, path2)) {
        Serial.println("File renamed");
    } else {
        Serial.println("Rename failed");
    }
}

void deleteFile(fs::FS &fs, const char * path){
    Serial.printf("Deleting file: %s\n", path);
    if(fs.remove(path)){
        Serial.println("File deleted");
    } else {
        Serial.println("Delete failed");
    }
}

void testFileIO(fs::FS &fs, const char * path){
    File file = fs.open(path);
    static uint8_t buf[512];
    size_t len = 0;
    uint32_t start = millis();
    uint32_t end = start;
    if(file){
        len = file.size();
        size_t flen = len;
        start = millis();
        while(len){
            size_t toRead = len;
            if(toRead > 512){
                toRead = 512;
            }
            file.read(buf, toRead);
            len -= toRead;
        }
        end = millis() - start;
        Serial.printf("%u bytes read for %u ms\r\n", flen, end);
        file.close();
    } else {
        Serial.println("Failed to open file for reading");
    }

    file = fs.open(path, FILE_WRITE);
    if(!file){
        Serial.println("Failed to open file for writing");
        return;
    }

    size_t i;
    start = millis();
    for(i=0; i<2048; i++){
        file.write(buf, 512);
    }
    end = millis() - start;
    Serial.printf("%u bytes written for %u ms\n", 2048 * 512, end);
    file.close();
}

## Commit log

2025-03-18 Log, Storage and pressure improvements
    Fixed:
    - Limit api calls
    - Giving correct status from presure
    - Fix log sepeerator for import in excel
    - added Total and Used Space
    [flight-computer.ino]
2025-03-21 Implemented camera and save to sd card (#2)
    * Implemented the camera functionality
    Implemented the camera functionality but i am getting a error conflict when using i2c from esp32 camera and where the sensors or on
    * Solved I2C issue
    Solved I2C issue
    * Delete flight-computer directory
    * Implemented camera and save to sd card
    Implemented camera and save to sd card
    [flight-computer.ino, sd_read_write.cpp]
2025-04-03 Working version 2.0
    Working version 2.0 before splitting sensors and webcam
2025-04-05 Version 3
    Working version, changed:
    - Removed camera function
    - Add led light cirle
    - Updated cropped HTML
2025-04-06 feat: Remove camera, add RGB LED indicators, correct altitude drop calculation, and add manual parachute release
    feat: Remove camera, add RGB LED indicators, correct altitude drop calculation, and add manual parachute release
    - Removed all camera and timelapse functionality.
    - Integrated an RGB LED ring for visual status (network connectivity, armed, released, unarmed).
    - Corrected altitude drop calculation by resetting relative altitude and drop extremes on arming.
    - Added a new web interface button for manual parachute release.
    - Updated documentation and assembly guide accordingly.
    [flight-computer.ino]
2025-04-08 issue: using multple triggers and RGB
    issue: using multple triggers and RGB led. Especially yhe rgb led too a lot of work
    [flight-computer.ino]
2025-04-08 feat: Add dedicated sensor calibration with improved parachute status updates (V3.2.0)
    feat: Add dedicated sensor calibration with improved parachute status updates (V3.2.0)
    - Introduced a new "Calibrate Sensors" command/button that resets both the baseline altitude and the accelerometer offsets (for X, Y, and Z axes) to zero their relative values.
    - Updated parachute state handling: if sensors are calibrated while the parachute is armed, the status changes to "calibrating" for visual feedback; the user must re-arm the system to re-establish the proper "armed" state.
    - Enhanced LED color support with explicit WS2812 wheel mappings:
    • Red (0) for armed
    • Blue (170) for unarmed
    •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
    [flight-computer.ino]
2025-04-12 Added file system manager
    Added file system manager
    Buttons not working also not visualization
    [flight-computer.ino]
2025-04-14 Changing to websockets (#3)
    * Working version before cleanup
    * Working version visualization
    Working version visualization
    * Release V3.3.0: Add Inline Comments & Anonymize API Credentials
    - Updated version number from V3.2.6 to V3.3.0 in the header.
    - Inserted comprehensive inline comments to clarify code functionality.
    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
2025-04-18 Update project to v3.4.0 – add web file manager, 3D viz support, axis config & live location; remove camera/timelapse
    Update project to v3.4.0 – add web file manager, 3D viz support, axis config & live location; remove camera/timelapse
2025-04-21 Updated readme with video
    Updated readme with video
    [testplan_v2.xlsx]
2025-05-03 Fixed lights
    Fixed lights
    [flight-computer.ino]
2025-05-03 Updated Led information and workings
    Updated Led information and workings
2025-07-15 Added SPIFF Log and warning LED
    Added SPIFF Log and warning LED
2025-07-16 Version 3.5 SPIFF logging and updated LED
    Version 3.5 SPIFF logging and updated LED
    [folder_file_structure.csv]
2025-07-18 Changed ledring to ledstrip
    Changed ledring to ledstrip
2025-07-22 Version 3.6.0 Three-Column Dashboard, Smarter SPIFFS Logging & Trigger Flexibility
    Version 3.6.0 Three-Column Dashboard, Smarter SPIFFS Logging & Trigger Flexibility
    [rocket_weight.xlsx]
2025-07-27 Made some small changes
    Made some small changes
    [rocket_weight.xlsx]
2025-08-24 feat: move dashboard & visualization to SPIFFS + add dual file manager (SD & SPIFFS)
    feat: move dashboard & visualization to SPIFFS + add dual file manager (SD & SPIFFS)
    [folder_file_structure.csv, rocket_weight.xlsx, testplan_v2.xlsx]
2025-08-24 Uploaded all 3D designs and update documentation
    Uploaded all 3D designs and update documentation
    [Battery Mount.stl, Bottle Connector.stl, Fin Type 1 A.stl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]
2025-10-01 Improved minor bugs
    Improved minor bugs
    [BOM.csv, ESP_Rocket_Shield.kicad_pcb, ESP_Rocket_Shield.kicad_sch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]
2025-10-11 Fixed backup spiff uploader
    Fixed backup spiff uploader
    [flight-computer.ino]
2025-10-12 v3.8.0 – Advanced Altitude Logic, Sensor Expansion & Smarter Data Handling (#4)
    * Added imrpoved altitude
    Added imrpoved altitude but this is non working version
    * API Key Back
    API Key Back
    * v3.8.0 – Advanced Altitude Logic, Sensor Expansion & Smarter Data Handling
    Version 3.8.0 introduces major improvements to flight telemetry accuracy and onboard data handling.
    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
